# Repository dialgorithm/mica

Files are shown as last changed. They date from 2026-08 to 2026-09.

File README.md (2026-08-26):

# mica

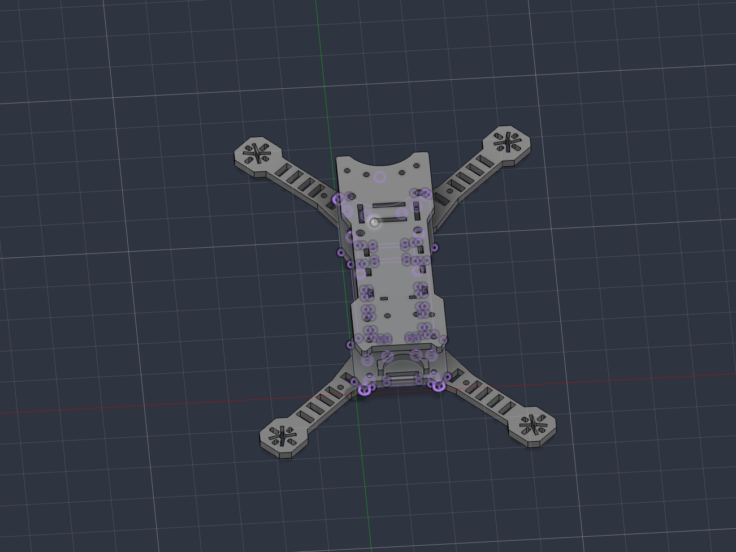
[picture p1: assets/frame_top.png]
mica PCB


**mica** is a compact wireless FPV drone built around an **XIAO ESP32-S3**, with a custom-designed flight controller and a custom 3D-printed frame. The project focuses on building a lightweight, self-contained drone platform with **ExpressLRS (ELRS)** control, custom electronics, and a mechanical design tailored specifically to the hardware.

it features:

- XIAO ESP32-S3 as the main flight controller
- Custom-designed flight controller PCB
- ExpressLRS (ELRS) for wireless control
- Custom 3D-printed frame

## design

mica is designed around keeping the electronics and mechanical structure compact while still leaving enough space for the components required for flight.

the flight controller is built around the XIAO ESP32-S3, with the supporting electronics integrated onto a custom PCB. the frame was designed specifically around the PCB and drone hardware rather than using an off-the-shelf frame.

the 3d-printed structure keeps the drone lightweight while providing mounting points for the electronics and other components. the overall layout is kept symmetrical to help maintain the center of gravity and make the drone predictable during flight.

## Schematics + PCB

Designed using KiCad.

| Schematic | PCB |
| --- | --- |
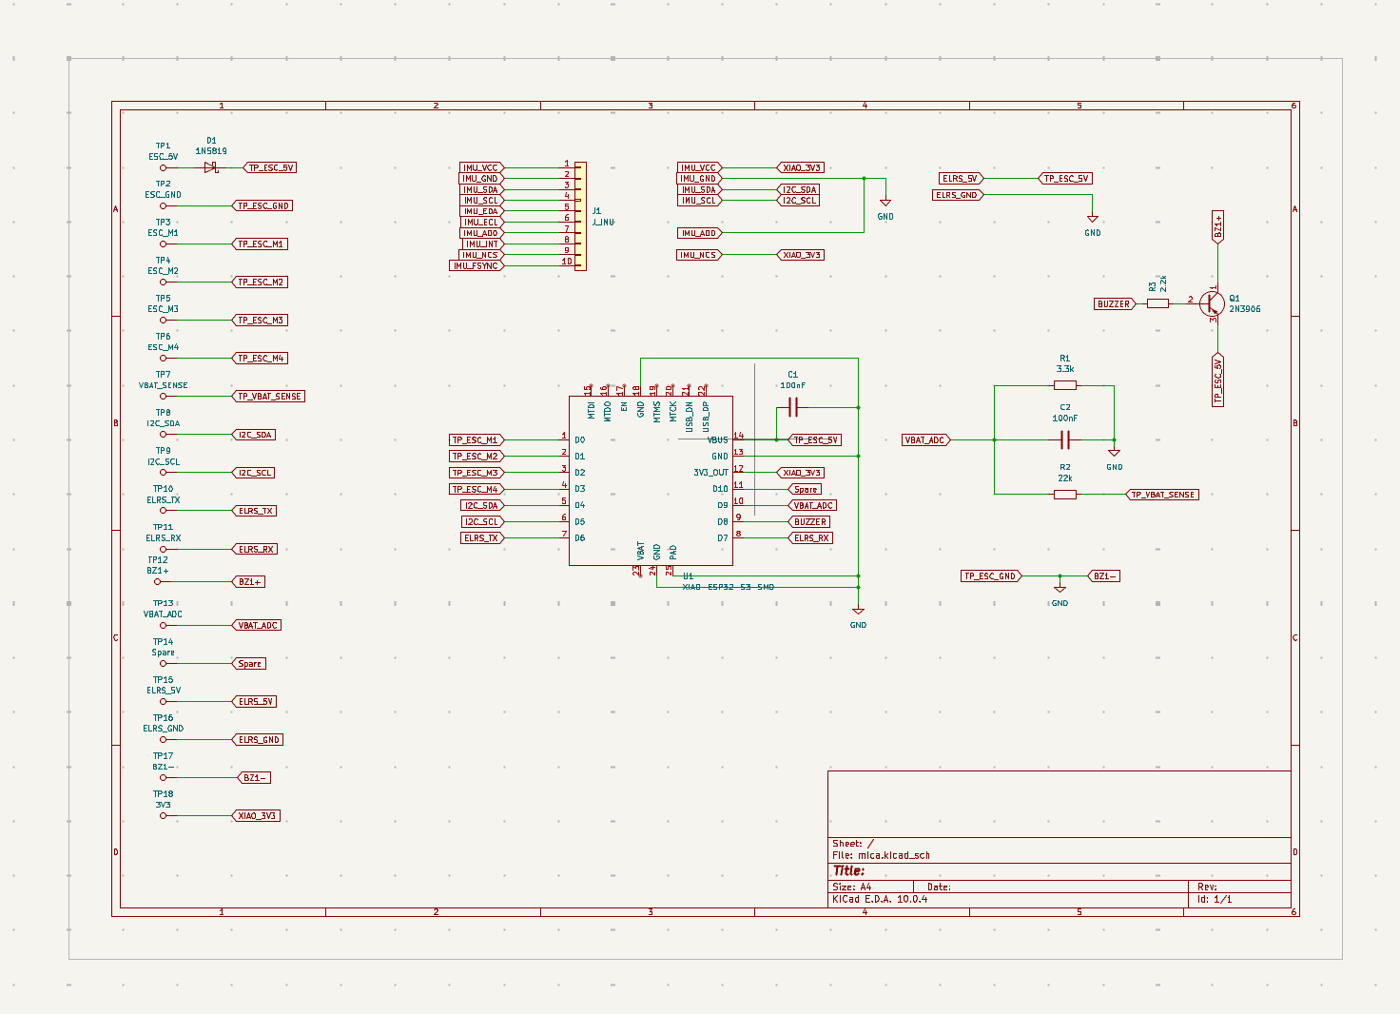
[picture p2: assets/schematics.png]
schematic
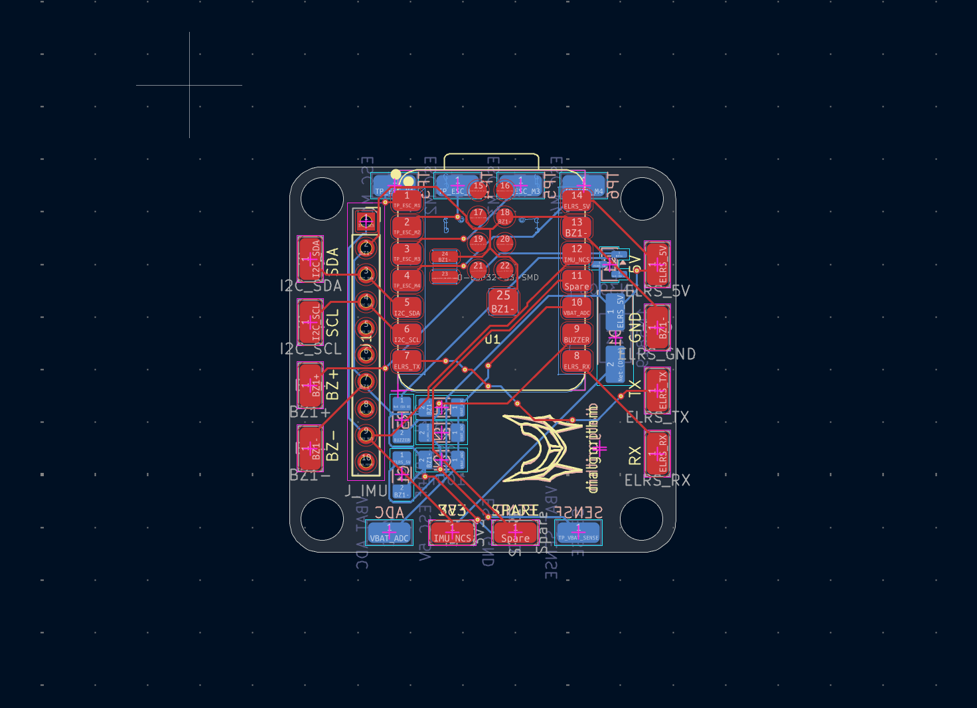
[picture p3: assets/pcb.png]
pcb
|  |  |

## CAD

final 3d mockup of the drone frame.

| | |
| --- | --- |
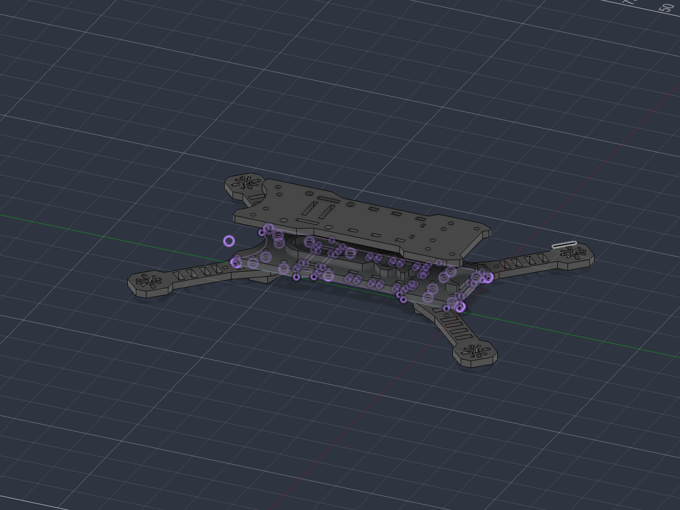
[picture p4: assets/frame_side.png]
side view
| top view |  |

the frame is 3d printable and was designed specifically around mica's electronics and component layout.

## BOM

the complete bill of materials is available in [`bom.csv`](bom.csv).

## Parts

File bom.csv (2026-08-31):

component | qty | cost | why | source
3d printed parts + shipping | 1 | $10 | to exist | https://printlegion.hackclub.com/
pcb | 1 | $9.5 | to exist | https://robu.in/product/online-pcb-manufacturing-service/
MicoAir 50A 4in1 ESC | 1 | $35.6 | control motor speed | https://fpvstore.in/product/micoair-50a-4in1-esc/
XIAO ESP32S3 | 1 | $11.5 | brain | https://robu.in/product/seeed-studio-xiao-esp32s3-2-4ghz-wifi-ble-5-0/
A2212 2200KV 6T | 4 | $16.8 | motors | https://robocraze.com/products/a2212-2200kv-brushless-outrunner-motor-aircraft-quadcopter-helicopter
1500mAh 30C 3S Lithium Polymer Battery Pack | 1 | $14.7 | power | https://probots.co.in/11-1v-2200mah-60c-3s-lipo-battery-lithium-polymer.html
5045 propellors | 6 | $3 | for lift | https://probots.co.in/5045-flat-head-forward-reverse-propeller-orange-pair.html
ExpressLRS RX24T 2.4G Receiver | 1 | $15.7 | to receive signals from transmitter | https://robu.in/product/expresslrs-rx24t-2-4g-receiver/
1N5819 diode | 1 | $0.5 | one way power to not fry electronics | https://robu.in/product/1n5819-ap-mcc-40v-1a-600mv1a-do-41-schottky-diodes-rohs/
100nF 1206 capacitor | 2 | $0.5 | to prevent surge | https://robu.in/product/100nf-1206-surface-mount-multilayer-ceramic-capacitor-pack-of-30/
2N3906 transistor | 1 | $0.5 | logic gate | https://robu.in/product/2n3906-ta-jcet-40v-625mw-10010ma1v-200ma-pnp-to-92-bipolar-bjt-rohs/
3.3K Ohm 1206 Resistor | 1 | $0.5 | current flow control | https://robu.in/product/3-3k-ohm-1-4w-1206-resistorreel-of-5000/
22k Ohm 1206 Resistor | 1 | $0.5 | current flow contorl | https://robu.in/product/22k-ohm-1-4w-1206-surface-mount-chip-resistor-pack-of-100/
2.2K Ohm 1206 Resistor | 1 | $0.5 | current flow control | https://robu.in/product/2-2k-ohm-1-4w-1206-resistorreel-of-5000/
GEPRC Smoke Stopper | 1 | $10.7 | prevent burndown of everything | https://zbotic.in/product/geprc-smoke-stopper/
MPU6050 IMU | 1 | $5 | position and orientation data
Total | - | $140 | - | -

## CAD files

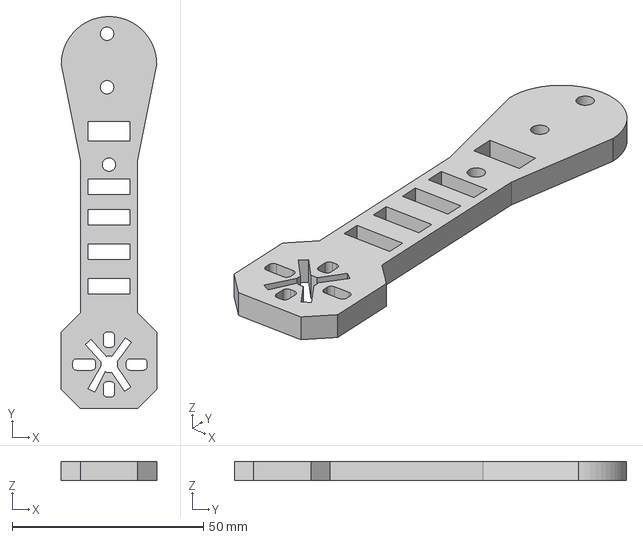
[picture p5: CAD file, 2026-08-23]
CAD/step/arm.step
25.0 x 102.5 x 5.00 mm

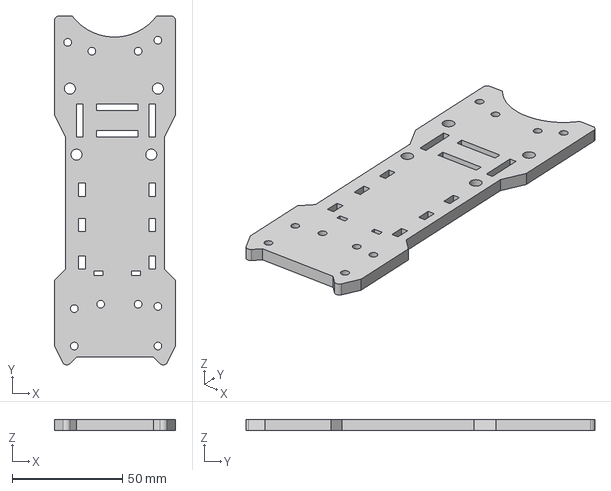
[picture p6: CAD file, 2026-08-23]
CAD/step/top.step
55.0 x 158.6 x 5.00 mm

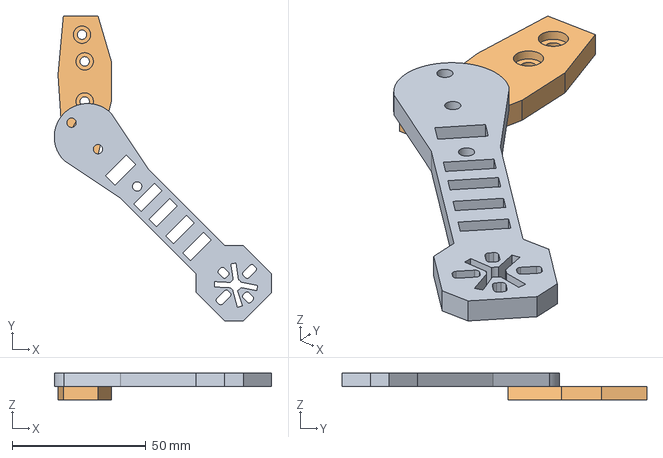
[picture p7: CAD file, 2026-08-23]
CAD/step/arm mount.step
81.4 x 114.2 x 10.00 mm

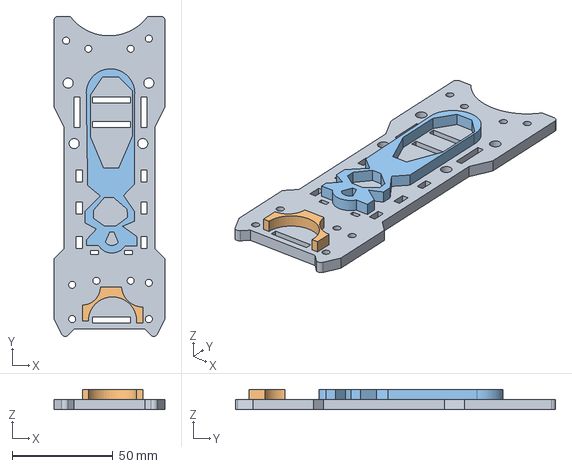
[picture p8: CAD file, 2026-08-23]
CAD/step/base.step
55.0 x 158.6 x 10.0 mm

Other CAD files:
CAD/main v1.f3d
CAD/stl/arm mount.stl
CAD/stl/arm.stl
CAD/stl/base.stl
CAD/stl/top.stl

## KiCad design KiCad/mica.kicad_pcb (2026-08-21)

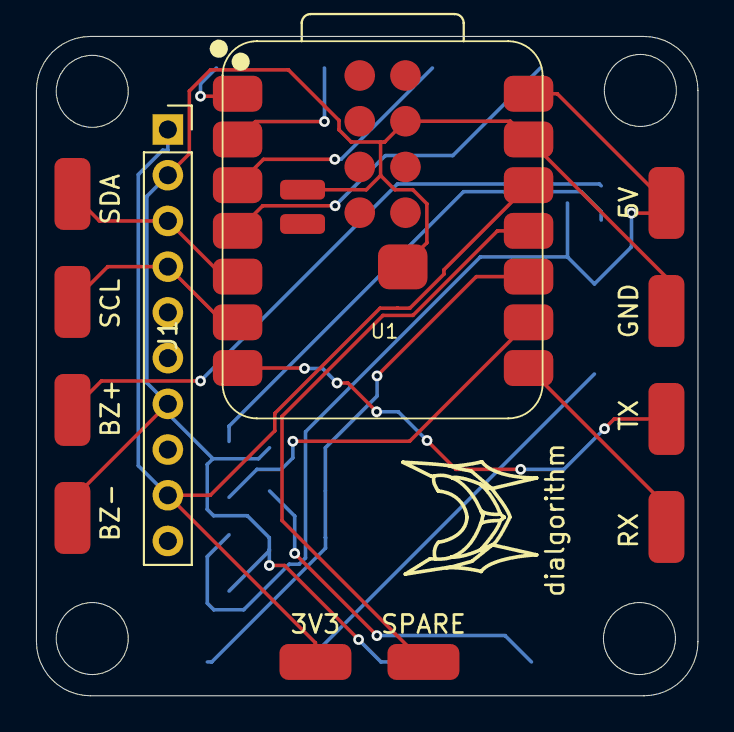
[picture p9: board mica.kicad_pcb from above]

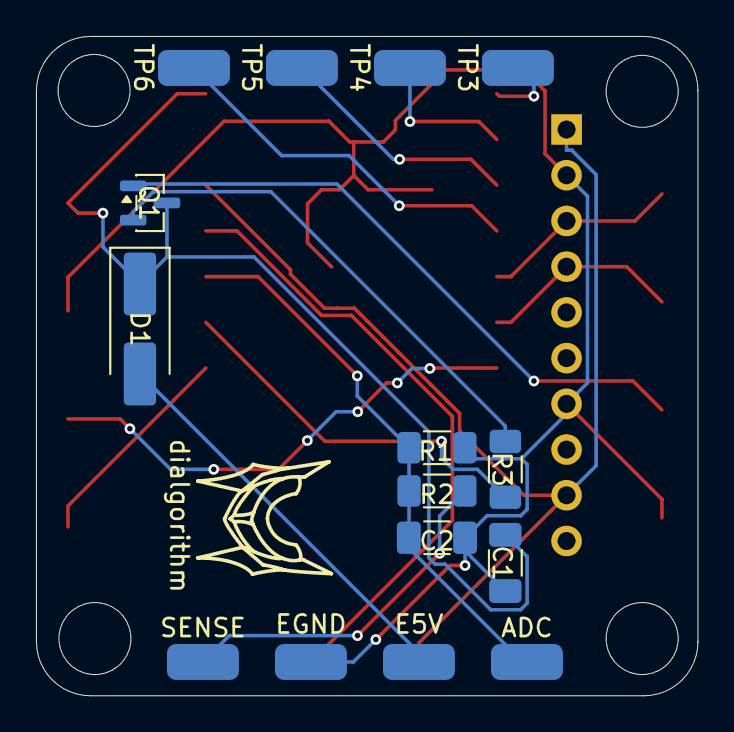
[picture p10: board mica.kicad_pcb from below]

Board: 2 copper layers, 36.8 x 36.6 mm, 29 parts (16 on the bottom side), 18 nets.

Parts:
3V3: 3V3; SolderWirePad_1x01_SMD_2x4mm
5V: ELRS_5V; SolderWirePad_1x01_SMD_2x4mm
ADC: VBAT_ADC; SolderWirePad_1x01_SMD_2x4mm
BZ+: BZ1+; SolderWirePad_1x01_SMD_2x4mm
BZ-: BZ1-; SolderWirePad_1x01_SMD_2x4mm
C1, C2: 100nF; C_1206_3216Metric_Pad1.33x1.80mm_HandSolder
D1: 1N5819; D_SMA_Handsoldering
E5V: ESC_5V; SolderWirePad_1x01_SMD_2x4mm
EGND: ESC_GND; SolderWirePad_1x01_SMD_2x4mm
GND: ELRS_GND; SolderWirePad_1x01_SMD_2x4mm
J1: J_IMU; PinSocket_1x10_P2.54mm_Vertical
Q1: 2N3906; SOT-23
R1: 3.3k; R_1206_3216Metric_Pad1.30x1.75mm_HandSolder
R2: 22k; R_1206_3216Metric_Pad1.30x1.75mm_HandSolder
R3: 2.2k; R_1206_3216Metric_Pad1.30x1.75mm_HandSolder
RX: ELRS_RX; SolderWirePad_1x01_SMD_2x4mm
SCL: I2C_SCL; SolderWirePad_1x01_SMD_2x4mm
SDA: I2C_SDA; SolderWirePad_1x01_SMD_2x4mm
SENSE: VBAT_SENSE; SolderWirePad_1x01_SMD_2x4mm
SPARE: Spare; SolderWirePad_1x01_SMD_2x4mm
TP3: ESC_M1; SolderWirePad_1x01_SMD_2x4mm
TP4: ESC_M2; SolderWirePad_1x01_SMD_2x4mm
TP5: ESC_M3; SolderWirePad_1x01_SMD_2x4mm
TP6: ESC_M4; SolderWirePad_1x01_SMD_2x4mm
TX: ELRS_TX; SolderWirePad_1x01_SMD_2x4mm
U1: XIAO-ESP32-S3-SMD
dialgorithm: dialgorithm
dialgorithm#2: dialgorithm

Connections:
BUZZER: R3.2, U1.9 (D8)
BZ1+: BZ+.1 (1_1), Q1.1 (C)
BZ1-: BZ-.1 (1_1), C1.2, C2.2, EGND.1 (1_1), GND.1 (1_1), J1.2, J1.7, R1.2, U1.13 (GND), U1.18 (GND), U1.24 (GND), U1.25 (PAD)
ELRS_5V: 5V.1 (1_1), C1.1, D1.1 (K), Q1.3 (E), U1.14 (VBUS)
ELRS_RX: RX.1 (1_1), U1.8 (D7)
ELRS_TX: TX.1 (1_1), U1.7 (D6)
I2C_SCL: J1.4, SCL.1 (1_1), U1.6 (D5)
I2C_SDA: J1.3, SDA.1 (1_1), U1.5 (D4)
IMU_NCS: 3V3.1 (1_1), J1.1, J1.9, U1.12 (3V3_OUT)
unnamed: D1.2 (A), E5V.1 (1_1)
unnamed: Q1.2 (B), R3.1
Spare: SPARE.1 (1_1), U1.11 (D10)
TP_ESC_M1: TP3.1 (1_1), U1.1 (D0)
TP_ESC_M2: TP4.1 (1_1), U1.2 (D1)
TP_ESC_M3: TP5.1 (1_1), U1.3 (D2)
TP_ESC_M4: TP6.1 (1_1), U1.4 (D3)
TP_VBAT_SENSE: R2.2, SENSE.1 (1_1)
VBAT_ADC: ADC.1 (1_1), C2.1, R1.1, R2.1, U1.10 (D9)

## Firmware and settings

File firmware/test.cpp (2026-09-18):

#include <Arduino.h>
#include <Wire.h>

// ============================================================
// MICA FLIGHT TEST FIRMWARE
// ============================================================
//
// Target: Seeed XIAO ESP32-S3
// Framework: Arduino-ESP32
//
// Motors MUST be physically disconnected during initial
// firmware/receiver testing.
// ============================================================


// ============================================================
// CONFIGURATION
// ============================================================

namespace Config {

    // ---------- I2C ----------
    constexpr int I2C_SDA = -1;       // TODO
    constexpr int I2C_SCL = -1;       // TODO

    // ---------- ELRS / CRSF ----------
    //
    // CRSF normally runs at 420000 baud, 8N1.
    //
    constexpr uint32_t CRSF_BAUD = 420000;

    constexpr int CRSF_RX_PIN = -1;   // TODO
    constexpr int CRSF_TX_PIN = -1;   // Usually unused

    // ---------- Motors ----------
    //
    // Quad X:
    //
    //       FRONT
    //
    //       M1      M2
    //        \      /
    //         \    /
    //          \  /
    //          /  \
    //         /    \
    //        /      \
    //       M3      M4
    //
    constexpr int MOTOR_1_PIN = -1;   // TODO
    constexpr int MOTOR_2_PIN = -1;   // TODO
    constexpr int MOTOR_3_PIN = -1;   // TODO
    constexpr int MOTOR_4_PIN = -1;   // TODO

    // PWM configuration
    constexpr uint32_t MOTOR_PWM_FREQ = 400;
    constexpr uint8_t MOTOR_PWM_BITS = 11;

    // ESC pulse range.
    //
    // If using standard PWM ESCs:
    //   1000 us = minimum
    //   2000 us = maximum
    //
    constexpr uint16_t MOTOR_MIN_US = 1000;
    constexpr uint16_t MOTOR_IDLE_US = 1050;
    constexpr uint16_t MOTOR_MAX_US = 2000;

    // ---------- Control ----------
    constexpr float LOOP_HZ = 500.0f;

    // Maximum commanded angular rates.
    constexpr float MAX_ROLL_RATE  = 360.0f;  // deg/s
    constexpr float MAX_PITCH_RATE = 360.0f;
    constexpr float MAX_YAW_RATE   = 180.0f;

    // Receiver channel mapping.
    //
    // Typical CRSF:
    // CH1 = Roll
    // CH2 = Pitch
    // CH3 = Throttle
    // CH4 = Yaw
    //
    constexpr int CH_ROLL     = 0;
    constexpr int CH_PITCH    = 1;
    constexpr int CH_THROTTLE = 2;
    constexpr int CH_YAW      = 3;
    constexpr int CH_ARM      = 4;

    // Receiver timeout.
    constexpr uint32_t RC_TIMEOUT_MS = 100;

    // Do not arm below this throttle.
    constexpr float ARM_THROTTLE_LIMIT = 0.05f;

    // ---------- PID ----------
    //
    // These are starting values only.
    // They MUST be tuned for the actual frame, motors,
    // propellers and IMU.
    //
    constexpr float ROLL_KP  = 0.8f;
    constexpr float ROLL_KI  = 0.15f;
    constexpr float ROLL_KD  = 0.015f;

    constexpr float PITCH_KP = 0.8f;
    constexpr float PITCH_KI = 0.15f;
    constexpr float PITCH_KD = 0.015f;

    constexpr float YAW_KP   = 0.8f;
    constexpr float YAW_KI   = 0.10f;
    constexpr float YAW_KD   = 0.0f;

    constexpr float PID_OUTPUT_LIMIT = 400.0f;

    // Integral limit prevents runaway accumulation.
    constexpr float PID_INTEGRAL_LIMIT = 100.0f;

    // ---------- Safety ----------
    constexpr bool REQUIRE_ARM_SWITCH = true;

    // Set true only after motor/ESC output has been verified.
    constexpr bool ENABLE_MOTORS = false;

}


// ============================================================
// BASIC UTILITIES
// ============================================================

float clampf(float x, float minValue, float maxValue)
{
    if (x < minValue) return minValue;
    if (x > maxValue) return maxValue;
    return x;
}

float mapFloat(
    float x,
    float inMin,
    float inMax,
    float outMin,
    float outMax
)
{
    return (x - inMin) *
           (outMax - outMin) /
           (inMax - inMin) +
           outMin;
}


// ============================================================
// VECTOR TYPES
// ============================================================

struct Vec3 {
    float x;
    float y;
    float z;
};

struct AttitudeRates {
    float roll;
    float pitch;
    float yaw;
};


// ============================================================
// IMU INTERFACE
// ============================================================
//
// Replace this implementation with the driver for the actual
// IMU on the mica PCB.
//
// The flight controller only needs gyro measurements in deg/s.
// ============================================================

class IMU
{
public:

    bool begin()
    {
        if (Config::I2C_SDA < 0 ||
            Config::I2C_SCL < 0) {

            Serial.println(
                "IMU: I2C pins not configured"
            );

            return false;
        }

        Wire.begin(
            Config::I2C_SDA,
            Config::I2C_SCL
        );

        // TODO:
        //
        // Initialize the actual IMU here.
        //
        // Example:
        //
        // imu.begin();
        // imu.setGyroRange(...);
        // imu.setGyroODR(...);

        Serial.println(
            "IMU: driver placeholder active"
        );

        return true;
    }


    bool readGyro(Vec3 &gyro)
    {
        // TODO:
        //
        // Replace with actual IMU read.
        //
        // gyro.x = ...
        // gyro.y = ...
        // gyro.z = ...

        gyro.x = 0.0f;
        gyro.y = 0.0f;
        gyro.z = 0.0f;

        return true;
    }


    bool calibrateGyro()
    {
        Serial.println(
            "IMU: keep aircraft completely still"
        );

        delay(1000);

        constexpr int SAMPLES = 1000;

        Vec3 sample;
        Vec3 sum = {0, 0, 0};

        for (int i = 0; i < SAMPLES; ++i) {

            if (!readGyro(sample)) {
                return false;
            }

            sum.x += sample.x;
            sum.y += sample.y;
            sum.z += sample.z;

            delay(2);
        }

        gyroBias.x = sum.x / SAMPLES;
        gyroBias.y = sum.y / SAMPLES;
        gyroBias.z = sum.z / SAMPLES;

        Serial.printf(
            "Gyro bias: %.3f %.3f %.3f\n",
            gyroBias.x,
            gyroBias.y,
            gyroBias.z
        );

        return true;
    }


    Vec3 getCorrectedGyro()
    {
        Vec3 raw;

        if (!readGyro(raw)) {
            return {0, 0, 0};
        }

        return {
            raw.x - gyroBias.x,
            raw.y - gyroBias.y,
            raw.z - gyroBias.z
        };
    }


private:

    Vec3 gyroBias = {0, 0, 0};
};


// ============================================================
// CRSF / ELRS RECEIVER
// ============================================================

class CRSF
{
public:

    bool begin()
    {
        if (Config::CRSF_RX_PIN < 0) {

            Serial.println(
                "CRSF: RX pin not configured"
            );

            return false;
        }

        Serial1.begin(
            Config::CRSF_BAUD,
            SERIAL_8N1,
            Config::CRSF_RX_PIN,
            Config::CRSF_TX_PIN
        );

        lastPacket = millis();

        Serial.println("CRSF: initialized");

        return true;
    }


    void update()
    {
        while (Serial1.available()) {

            uint8_t byte = Serial1.read();

            parseByte(byte);
        }
    }


    bool connected() const
    {
        return
            millis() - lastPacket <
            Config::RC_TIMEOUT_MS;
    }


    float channel(int index) const
    {
        if (index < 0 || index >= 16) {
            return 0;
        }

        return channels[index];
    }


private:

    uint8_t packet[64];
    uint8_t packetIndex = 0;
    uint8_t packetLength = 0;

    float channels[16] = {0};

    uint32_t lastPacket = 0;


    void parseByte(uint8_t byte)
    {
        // CRSF packets:
        //
        // [address]
        // [length]
        // [type]
        // [payload]
        // [CRC]

        if (packetIndex == 0) {

            // Typical CRSF device addresses.
            if (byte != 0xC8 &&
                byte != 0xEA &&
                byte != 0xEC &&
                byte != 0xEE) {
                return;
            }

            packet[packetIndex++] = byte;
            return;
        }


        if (packetIndex == 1) {

            packetLength = byte;

            if (packetLength < 2 ||
                packetLength > 62) {

                packetIndex = 0;
                return;
            }

            packet[packetIndex++] = byte;
            return;
        }


        packet[packetIndex++] = byte;


        if (packetIndex >= packetLength + 2) {

            processPacket();

            packetIndex = 0;
        }
    }


    void processPacket()
    {
        uint8_t type = packet[2];

        // CRSF packed RC channels
        constexpr uint8_t TYPE_RC_CHANNELS = 0x16;

        if (type != TYPE_RC_CHANNELS) {
            return;
        }

        // Need 16 channels * 11 bits = 176 bits = 22 bytes.
        if (packetLength < 24) {
            return;
        }

        uint32_t bits = 0;
        int bitCount = 0;
        int byteIndex = 3;

        for (int ch = 0; ch < 16; ch++) {

            uint16_t value = 0;

            for (int b = 0; b < 11; b++) {

                int bitPosition = bitCount + b;

                int sourceByte =
                    byteIndex + bitPosition / 8;

                int sourceBit =
                    bitPosition % 8;

                if (packet[sourceByte] &
                    (1 << sourceBit)) {

                    value |= (1 << b);
                }
            }

            bitCount += 11;

            //
            // CRSF channel range is approximately
            // 172 ... 1811.
            //
            channels[ch] = mapFloat(
                value,
                172,
                1811,
                -1.0f,
                1.0f
            );
        }

        // Throttle is special:
        //
        // Map CH3 from approximately
        // 172 ... 1811 to 0 ... 1.
        channels[Config::CH_THROTTLE] =
            clampf(
                mapFloat(
                    getRawChannel(
                        Config::CH_THROTTLE
                    ),
                    172,
                    1811,
                    0,
                    1
                ),
                0,
                1
            );

        lastPacket = millis();
    }


    float getRawChannel(int index) const
    {
        //
        // This implementation stores normalized values.
        // For a production implementation, retain raw
        // 11-bit values separately.
        //
        return mapFloat(
            channels[index],
            -1,
            1,
            172,
            1811
        );
    }
};


// ============================================================
// PID CONTROLLER
// ============================================================

class PID
{
public:

    PID(
        float kp,
        float ki,
        float kd
    )
        : kp(kp),
          ki(ki),
          kd(kd)
    {}


    float update(
        float target,
        float measurement,
        float dt
    )
    {
        float error =
            target - measurement;

        integral +=
            error * dt;

        integral = clampf(
            integral,
            -Config::PID_INTEGRAL_LIMIT,
            Config::PID_INTEGRAL_LIMIT
        );

        float derivative = 0;

        if (initialized) {

            derivative =
                (error - previousError) / dt;
        }
        else {

            initialized = true;
        }

        previousError = error;

        float output =
            kp * error +
            ki * integral +
            kd * derivative;

        return clampf(
            output,
            -Config::PID_OUTPUT_LIMIT,
            Config::PID_OUTPUT_LIMIT
        );
    }


    void reset()
    {
        integral = 0;
        previousError = 0;
        initialized = false;
    }


private:

    float kp;
    float ki;
    float kd;

    float integral = 0;
    float previousError = 0;

    bool initialized = false;
};


// ============================================================
// MOTOR OUTPUT
// ============================================================

class Motors
{
public:

    void begin()
    {
        pinMode(Config::MOTOR_1_PIN, OUTPUT);
        pinMode(Config::MOTOR_2_PIN, OUTPUT);
        pinMode(Config::MOTOR_3_PIN, OUTPUT);
        pinMode(Config::MOTOR_4_PIN, OUTPUT);

        //
        // Actual LEDC setup should be adapted to the installed
        // Arduino-ESP32 version.
        //
        // For initial development, keep motor output disabled.
        //

        stop();
    }


    void writeMicroseconds(
        uint16_t m1,
        uint16_t m2,
        uint16_t m3,
        uint16_t m4
    )
    {
        if (!Config::ENABLE_MOTORS) {
            return;
        }

        m1 = constrain(
            m1,
            Config::MOTOR_MIN_US,
            Config::MOTOR_MAX_US
        );

        m2 = constrain(
            m2,
            Config::MOTOR_MIN_US,
            Config::MOTOR_MAX_US
        );

        m3 = constrain(
            m3,
            Config::MOTOR_MIN_US,
            Config::MOTOR_MAX_US
        );

        m4 = constrain(
            m4,
            Config::MOTOR_MIN_US,
            Config::MOTOR_MAX_US
        );

        //
        // TODO:
        // Convert microseconds into the PWM representation
        // required by your ESC protocol.
        //
    }


    void stop()
    {
        //
        // TODO:
        // Send the ESC's minimum/disarmed signal.
        //
    }
};


// ============================================================
// FLIGHT CONTROLLER
// ============================================================

class FlightController
{
public:

    void begin()
    {
        rollPID = PID(
            Config::ROLL_KP,
            Config::ROLL_KI,
            Config::ROLL_KD
        );

        pitchPID = PID(
            Config::PITCH_KP,
            Config::PITCH_KI,
            Config::PITCH_KD
        );

        yawPID = PID(
            Config::YAW_KP,
            Config::YAW_KI,
            Config::YAW_KD
        );
    }


    void update(
        float dt,
        const Vec3 &gyro,
        const CRSF &receiver,
        Motors &motors
    )
    {
        bool receiverOK =
            receiver.connected();


        float throttle =
            receiver.channel(
                Config::CH_THROTTLE
            );

        float armChannel =
            receiver.channel(
                Config::CH_ARM
            );


        //
        // ARM CONDITIONS
        //

        bool armRequest =
            armChannel > 0.5f;

        bool throttleLow =
            throttle <
            Config::ARM_THROTTLE_LIMIT;


        if (!receiverOK) {

            armed = false;
        }


        if (Config::REQUIRE_ARM_SWITCH) {

            if (!armRequest) {
                armed = false;
            }
        }


        if (armRequest &&
            throttleLow &&
            receiverOK) {

            armed = true;
        }


        //
        // DISARMED
        //

        if (!armed) {

            rollPID.reset();
            pitchPID.reset();
            yawPID.reset();

            motors.stop();

            return;
        }


        //
        // RECEIVER COMMANDS
        //

        float rollCommand =
            receiver.channel(
                Config::CH_ROLL
            );

        float pitchCommand =
            receiver.channel(
                Config::CH_PITCH
            );

        float yawCommand =
            receiver.channel(
                Config::CH_YAW
            );


        float rollTarget =
            rollCommand *
            Config::MAX_ROLL_RATE;

        float pitchTarget =
            pitchCommand *
            Config::MAX_PITCH_RATE;

        float yawTarget =
            yawCommand *
            Config::MAX_YAW_RATE;


        //
        // RATE PID
        //

        float rollOutput =
            rollPID.update(
                rollTarget,
                gyro.x,
                dt
            );

        float pitchOutput =
            pitchPID.update(
                pitchTarget,
                gyro.y,
                dt
            );

        float yawOutput =
            yawPID.update(
                yawTarget,
                gyro.z,
                dt
            );


        //
        // THROTTLE
        //

        float baseThrottle =
            mapFloat(
                throttle,
                0.0f,
                1.0f,
                Config::MOTOR_IDLE_US,
                Config::MOTOR_MAX_US
            );


        //
        // QUAD-X MIXER
        //
        //
        // Verify this orientation against the actual
        // physical motor positions and rotation directions.
        //
        //
        // M1 = front-left
        // M2 = front-right
        // M3 = rear-right
        // M4 = rear-left
        //

        float m1 =
            baseThrottle
            + rollOutput
            + pitchOutput
            - yawOutput;

        float m2 =
            baseThrottle
            - rollOutput
            + pitchOutput
            + yawOutput;

        float m3 =
            baseThrottle
            - rollOutput
            - pitchOutput
            - yawOutput;

        float m4 =
            baseThrottle
            + rollOutput
            - pitchOutput
            + yawOutput;


        //
        // Prevent mixer saturation from producing values
        // outside the ESC range.
        //

        m1 = clampf(
            m1,
            Config::MOTOR_MIN_US,
            Config::MOTOR_MAX_US
        );

        m2 = clampf(
            m2,
            Config::MOTOR_MIN_US,
            Config::MOTOR_MAX_US
        );

        m3 = clampf(
            m3,
            Config::MOTOR_MIN_US,
            Config::MOTOR_MAX_US
        );

        m4 = clampf(
            m4,
            Config::MOTOR_MIN_US,
            Config::MOTOR_MAX_US
        );


        motors.writeMicroseconds(
            (uint16_t)m1,
            (uint16_t)m2,
            (uint16_t)m3,
            (uint16_t)m4
        );
    }


    bool isArmed() const
    {
        return armed;
    }


private:

    bool armed = false;

    PID rollPID{
        Config::ROLL_KP,
        Config::ROLL_KI,
        Config::ROLL_KD
    };

    PID pitchPID{
        Config::PITCH_KP,
        Config::PITCH_KI,
        Config::PITCH_KD
    };

    PID yawPID{
        Config::YAW_KP,
        Config::YAW_KI,
        Config::YAW_KD
    };
};


// ============================================================
// GLOBAL OBJECTS
// ============================================================

IMU imu;
CRSF receiver;
Motors motors;
FlightController flightController;


// ============================================================
// TIMING
// ============================================================

uint32_t lastLoopMicros = 0;
uint32_t lastDebugMillis = 0;


// ============================================================
// SETUP
// ============================================================

void setup()
{
    Serial.begin(115200);

    delay(1000);

    Serial.println();
    Serial.println("====================");
    Serial.println("       MICA FC      ");
    Serial.println("====================");


    //
    // HARDWARE CHECK
    //

    if (!imu.begin()) {

        Serial.println(
            "ERROR: IMU initialization failed"
        );
    }

    imu.calibrateGyro();


    if (!receiver.begin()) {

        Serial.println(
            "WARNING: CRSF not configured"
        );
    }


    motors.begin();

    flightController.begin();


    //
    // ALWAYS START DISARMED
    //

    motors.stop();


    lastLoopMicros =
        micros();


    Serial.println(
        "MICA firmware ready"
    );

    Serial.println(
        "Motors remain disabled until "
        "ENABLE_MOTORS is changed."
    );
}


// ============================================================
// LOOP
// ============================================================

void loop()
{
    //
    // Receiver parsing should run continuously.
    //

    receiver.update();


    //
    // Fixed-rate control loop.
    //

    constexpr uint32_t LOOP_PERIOD_US =
        (uint32_t)(
            1000000.0f /
            Config::LOOP_HZ
        );


    uint32_t now =
        micros();


    if (
        (uint32_t)(
            now - lastLoopMicros
        ) < LOOP_PERIOD_US
    ) {
        return;
    }


    uint32_t elapsed =
        now - lastLoopMicros;

    lastLoopMicros = now;


    float dt =
        elapsed / 1000000.0f;


    //
    // Protect against timing glitches.
    //

    if (dt <= 0 ||
        dt > 0.02f) {

        dt =
            1.0f /
            Config::LOOP_HZ;
    }


    //
    // Read IMU.
    //

    Vec3 gyro =
        imu.getCorrectedGyro();


    //
    // Run flight controller.
    //

    flightController.update(
        dt,
        gyro,
        receiver,
        motors
    );


    //
    // DEBUG TELEMETRY
    //

    if (
        millis() -
        lastDebugMillis > 250
    ) {

        lastDebugMillis =
            millis();


        Serial.printf(
            "RC=%d ARM=%d "
            "T=%.2f "
            "GYRO=%.1f %.1f %.1f "
            "FC=%s\n",

            receiver.connected(),

            flightController.isArmed(),

            receiver.channel(
                Config::CH_THROTTLE
            ),

            gyro.x,
            gyro.y,
            gyro.z,

            flightController.isArmed()
                ? "ARMED"
                : "DISARMED"
        );
    }
}
